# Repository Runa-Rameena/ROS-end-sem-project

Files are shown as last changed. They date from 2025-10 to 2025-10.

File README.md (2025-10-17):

# Snake Robot - Simulation & Hardware

## What We Simulated

We developed a complete ROS2 Humble + Gazebo Classic simulation of a modular snake robot with 33 articulated joints. The simulation models an 8-segment snake robot that performs serpentine locomotion through coordinated joint movements.

**Simulation Features:**
- 33 revolute joints with ±90° range of motion
- URDF/Xacro robot model with realistic physics properties
- ros2_control framework with joint_trajectory_controller
- Phase-shifted sinusoidal wave control algorithm
- Real-time visualization in RViz and Gazebo
- Keyboard teleop control (forward, backward, stop)
- Tunable gait parameters (amplitude, frequency, phase offset)

**Control Algorithm:**
Each joint follows a traveling wave equation:
θᵢ(t) = A · sin(ωt + φᵢ)
This creates smooth serpentine undulation where wave propagates along the body.

## What We Built in Hardware

We fabricated a physical 8-segment snake robot using 3D-printed PLA components and off-the-shelf electronics.

**Hardware Components:**
- 8× 3D-printed body segments (75×45×35 mm each)
- 1× head segment (85×45×45 mm) - houses ESP32 controller
- 1× tail segment (65×45×35 mm) - battery compartment
- 8× SG90 micro servo motors (4.8-6.0V, ±90°)
- ESP32 microcontroller (Arduino-compatible)
- 2S Li-Po battery (7.4V, 1000-2000 mAh)
- 5V 6A Buck converter for stable power regulation
- 470µF + 0.1µF capacitors for voltage filtering

**Power System:**
2S Li-Po (7.4V) → Buck Converter → 5V regulated output → Servos + ESP32

**Control Implementation:**
The same sinusoidal control algorithm from simulation was programmed into the ESP32. Each servo receives PWM signals with phase-shifted timing to create the traveling wave motion.

**Total Weight:** ~520g  

## Simulation-to-Hardware Validation

The hardware closely replicated the simulated motion:
- Amplitude: 25-30° (simulation: 25-35°)
- Frequency: 1-2.5 Hz (simulation: 1-3 Hz)  
- Phase coordination: 90%+ match between virtual and physical robot
- Continuous serpentine motion for 30+ minutes on single charge

Both systems use identical control logic, proving the simulation accurately predicts real-world snake locomotion.

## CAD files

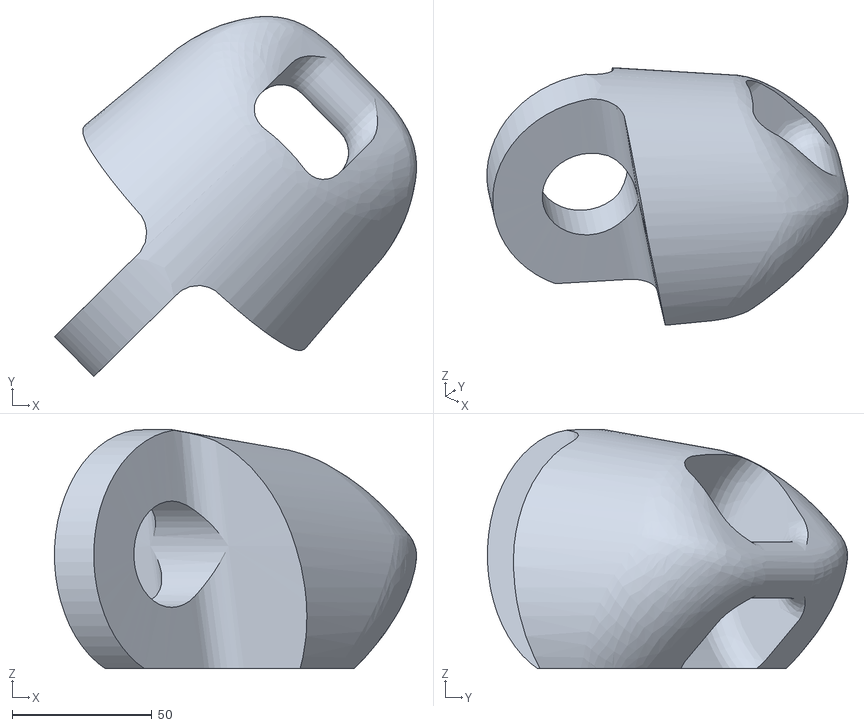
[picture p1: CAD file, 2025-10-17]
meshes/31_1.stl
129.4 x 128.7 x 85.5

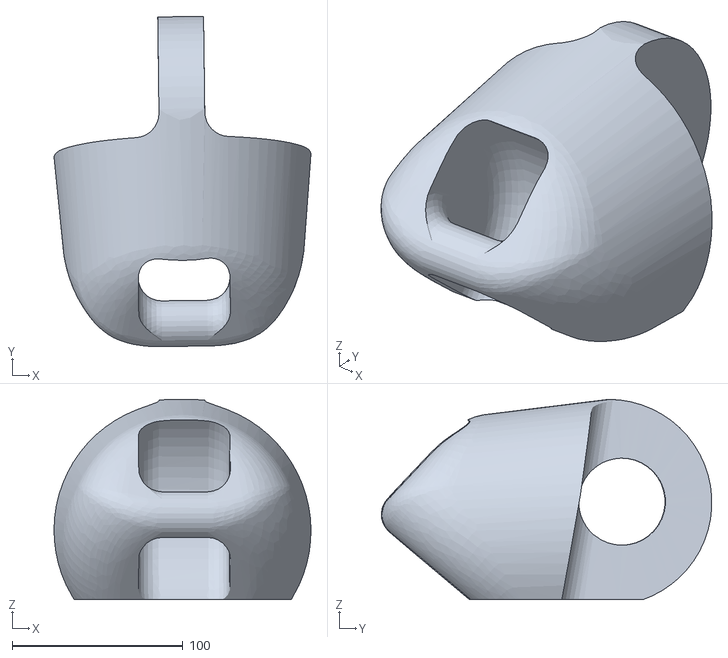
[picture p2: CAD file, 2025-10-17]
meshes/15_1.stl
150.5 x 193.5 x 117.2

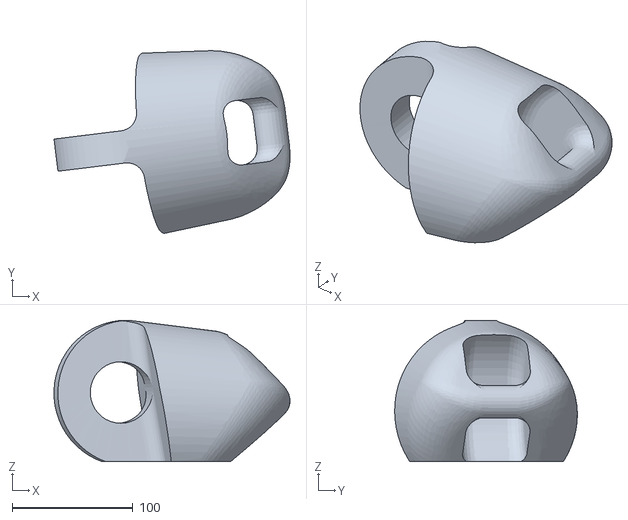
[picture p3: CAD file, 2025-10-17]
meshes/20_1.stl
195.7 x 151.5 x 117.2

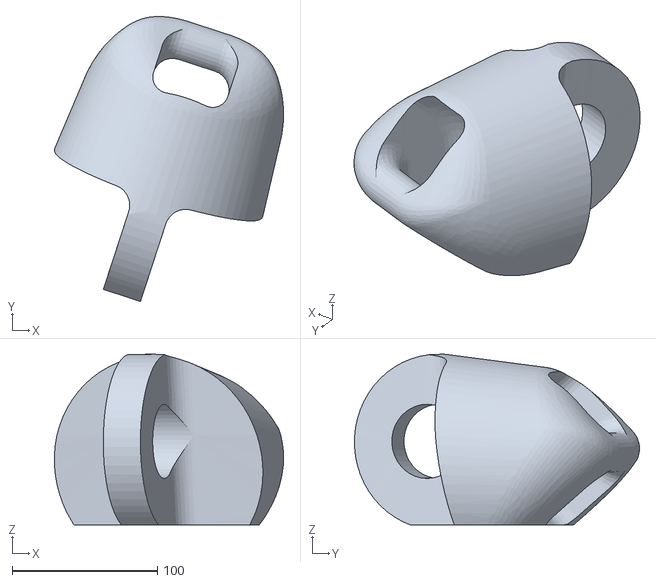
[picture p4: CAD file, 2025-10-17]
meshes/24_1.stl
157.5 x 195.9 x 117.2

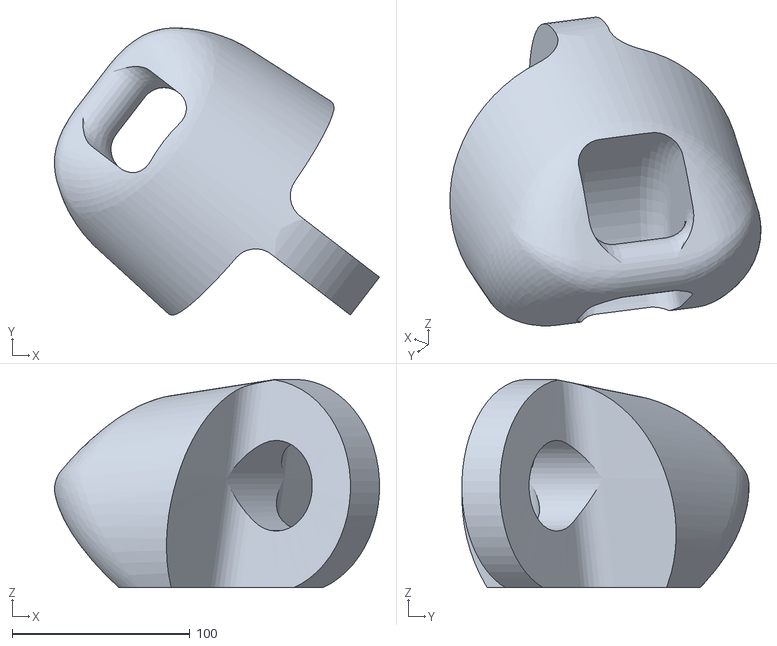
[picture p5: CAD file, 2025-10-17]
meshes/06_1.stl
182.8 x 161.5 x 117.2

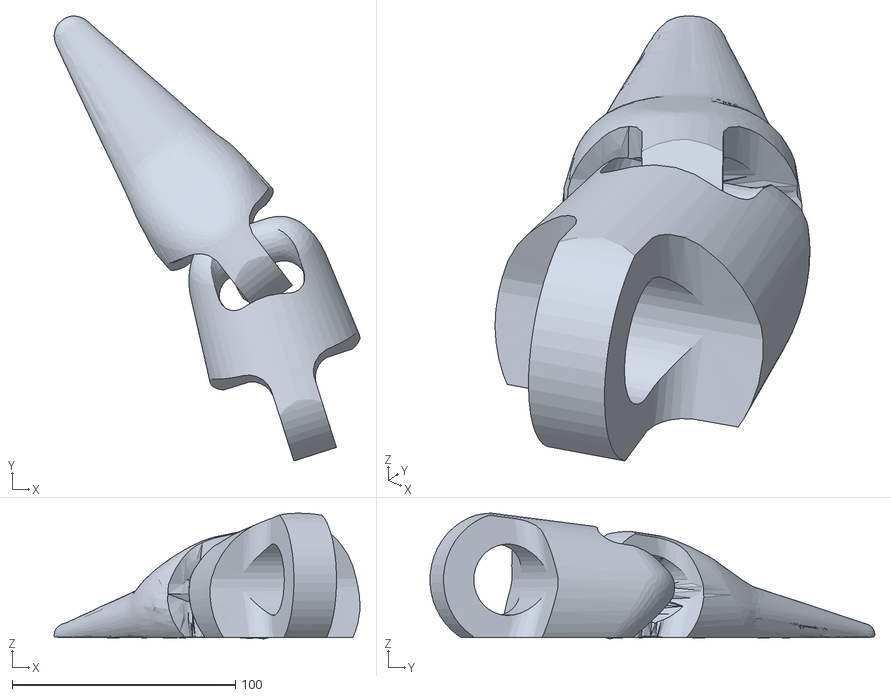
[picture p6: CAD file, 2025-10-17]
meshes/tail_1.stl
136.9 x 199.2 x 56.4

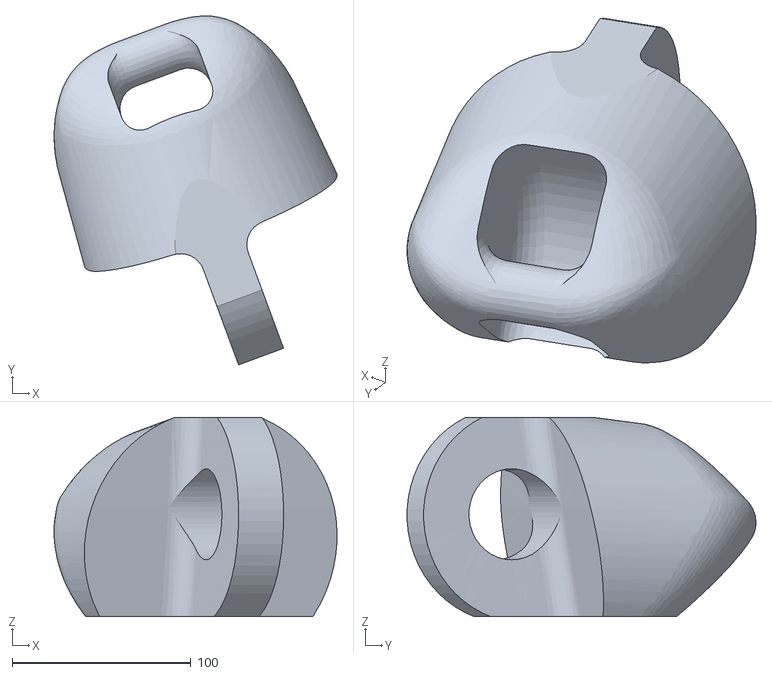
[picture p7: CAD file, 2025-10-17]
meshes/03_1.stl
158.4 x 195.3 x 111.7

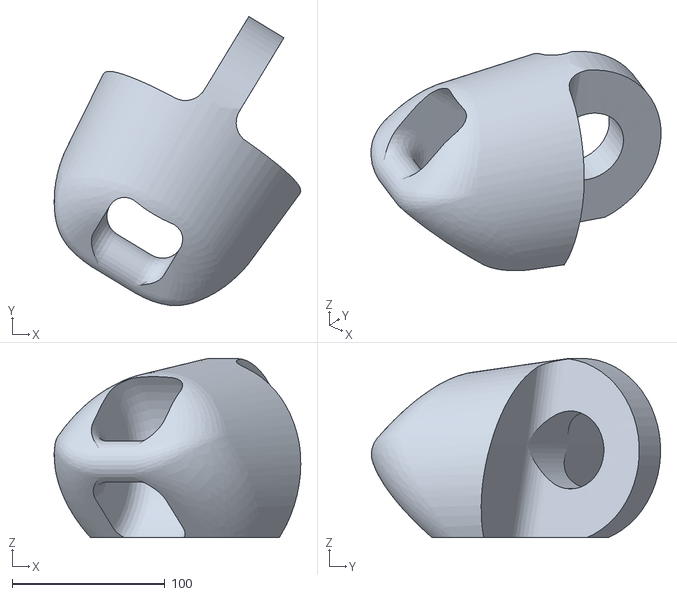
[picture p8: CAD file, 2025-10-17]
meshes/13_1.stl
161.2 x 188.9 x 117.2

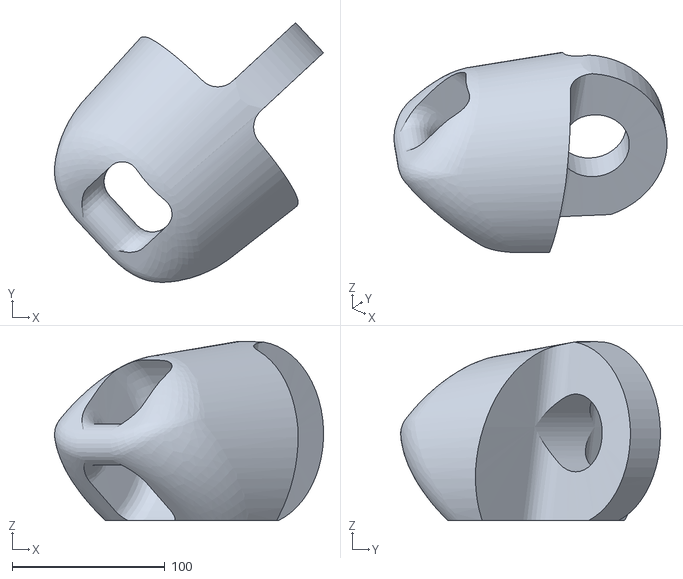
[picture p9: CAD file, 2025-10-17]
meshes/12_1.stl
176.2 x 170.1 x 117.2

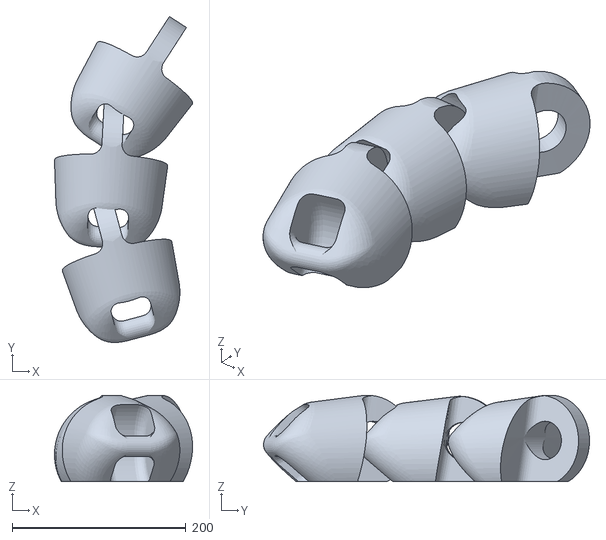
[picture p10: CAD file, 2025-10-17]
meshes/28_1.stl
159.0 x 375.3 x 99.5

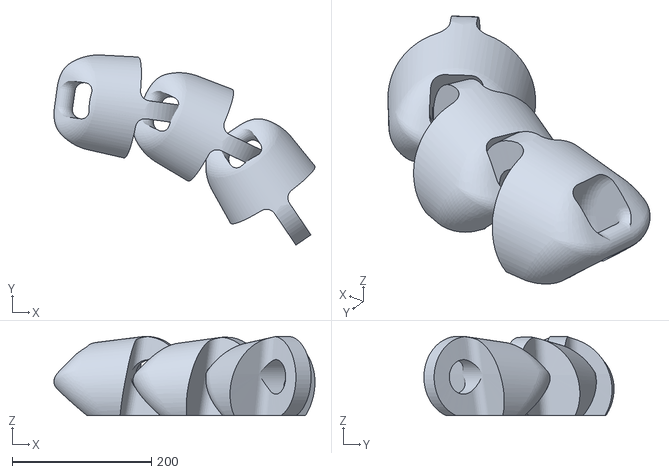
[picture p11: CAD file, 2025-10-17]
meshes/26_1.stl
374.8 x 273.0 x 113.9

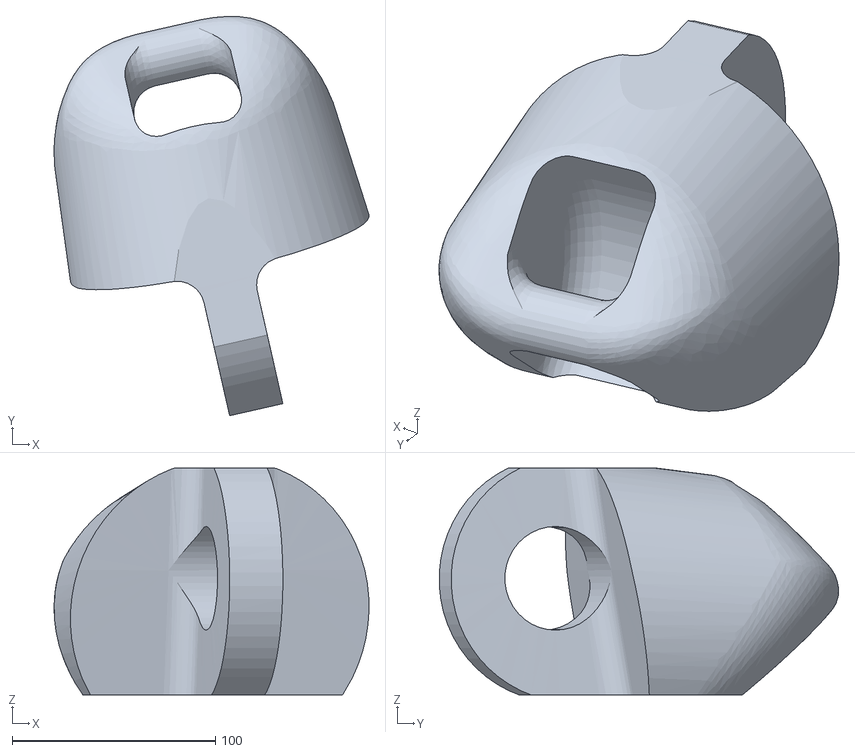
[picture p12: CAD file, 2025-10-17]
meshes/01_1.stl
155.0 x 196.5 x 111.6

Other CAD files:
meshes/09_1.stl
meshes/14_1.stl
meshes/11_1.stl
meshes/22_1.stl
meshes/04_1.stl
meshes/16_1.stl
meshes/02_1.stl
meshes/05_1.stl
meshes/07_1.stl
meshes/08_1.stl
meshes/10_1.stl
meshes/17_1.stl
meshes/18_1.stl
meshes/19_1.stl
meshes/21_1.stl
meshes/23_1.stl
meshes/25_1.stl
meshes/27_1.stl
meshes/29_1.stl
meshes/30_1.stl
meshes/32_1.stl
meshes/33_1.stl
meshes/base_link.stl

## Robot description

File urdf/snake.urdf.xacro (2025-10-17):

<?xml version="1.0"?>
<robot xmlns:xacro="http://www.ros.org/wiki/xacro" name="snake_robot">

  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
  <xacro:include filename="$(find snake_robot)/urdf/materials.xacro"/>

  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
  <link name="world"/>

  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
  <link name="base_link">
    <inertial>
      <origin xyz="0 0 0" rpy="0 0 0"/>
      <mass value="2.0"/>
      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
    </inertial>
    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
  </link>

  <joint name="world_joint" type="fixed">
    <parent link="world"/>
    <child link="base_link"/>
  </joint>

  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
  <link name="link1">
    <inertial>
      <origin xyz="0 0 0" rpy="0 0 0"/>
      <mass value="1.0"/>
      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
    </inertial>
    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
  </link>

  <joint name="joint1" type="revolute">
    <parent link="base_link"/>
    <child link="link1"/>
    <origin xyz="0.15 0 0" rpy="0 0 0"/>
    <axis xyz="0 0 1"/>
    <limit effort="10" velocity="2.0" lower="-1.57" upper="1.57"/>
    <dynamics damping="0.5" friction="0.1"/>
    <safety_controller k_position="100" k_velocity="10" soft_lower_limit="-1.5" soft_upper_limit="1.5"/>
  </joint>

  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
  <link name="link2">
    <inertial>
      <origin xyz="0 0 0" rpy="0 0 0"/>
      <mass value="1.0"/>
      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
    </inertial>
    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
  </link>

  <joint name="joint2" type="revolute">
    <parent link="link1"/>
    <child link="link2"/>
    <origin xyz="0.15 0 0" rpy="0 0 0"/>
    <axis xyz="0 0 1"/>
    <limit effort="10" velocity="2.0" lower="-1.57" upper="1.57"/>
    <dynamics damping="0.5" friction="0.1"/>
    <safety_controller k_position="100" k_velocity="10" soft_lower_limit="-1.5" soft_upper_limit="1.5"/>
  </joint>

  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
  <xacro:macro name="snake_segment" params="n">
    <link name="link${n}">
      <inertial>
        <origin xyz="0 0 0" rpy="0 0 0"/>
        <mass value="1.0"/>
        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
      </inertial>
      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
    </link>

    <joint name="joint${n}" type="revolute">
      <parent link="link${n - 1}"/>
      <child link="link${n}"/>
      <origin xyz="0.15 0 0" rpy="0 0 0"/>
      <axis xyz="0 0 1"/>
      <limit effort="10" velocity="2.0" lower="-1.57" upper="1.57"/>
      <dynamics damping="0.5" friction="0.1"/>
      <safety_controller k_position="100" k_velocity="10" soft_lower_limit="-1.5" soft_upper_limit="1.5"/>
    </joint>
  </xacro:macro>

  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
  <xacro:snake_segment n="3"/>
  <xacro:snake_segment n="4"/>
  <xacro:snake_segment n="5"/>
  <xacro:snake_segment n="6"/>
  <xacro:snake_segment n="7"/>
  <xacro:snake_segment n="8"/>
  <xacro:snake_segment n="9"/>
  <xacro:snake_segment n="10"/>
  <xacro:snake_segment n="11"/>
  <xacro:snake_segment n="12"/>
  <xacro:snake_segment n="13"/>
  <xacro:snake_segment n="14"/>
  <xacro:snake_segment n="15"/>
  <xacro:snake_segment n="16"/>
  <xacro:snake_segment n="17"/>
  <xacro:snake_segment n="18"/>
  <xacro:snake_segment n="19"/>
  <xacro:snake_segment n="20"/>
  <xacro:snake_segment n="21"/>
  <xacro:snake_segment n="22"/>
  <xacro:snake_segment n="23"/>
  <xacro:snake_segment n="24"/>
  <xacro:snake_segment n="25"/>
  <xacro:snake_segment n="26"/>
  <xacro:snake_segment n="27"/>
  <xacro:snake_segment n="28"/>
  <xacro:snake_segment n="29"/>
  <xacro:snake_segment n="30"/>
  <xacro:snake_segment n="31"/>
  <xacro:snake_segment n="32"/>
  <xacro:snake_segment n="33"/>

  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
  <link name="tail_link">
    <inertial>
      <origin xyz="0 0 0" rpy="0 0 0"/>
      <mass value="0.5"/>
      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
    </inertial>
    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
  </link>

  <joint name="joint34" type="fixed">
    <parent link="link33"/>
    <child link="tail_link"/>
    <origin xyz="0.15 0 0" rpy="0 0 0"/>
  </joint>

  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
  <ros2_control name="SnakeRobotSystem" type="system">
    <hardware>
      <plugin>gazebo_ros2_control/GazeboSystem</plugin>
    </hardware>

    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
    <joint name="joint1">
      <command_interface name="position"/>
      <state_interface name="position"/>
      <state_interface name="velocity"/>
      <state_interface name="effort"/>
      <param name="min">-1.57</param>
      <param name="max">1.57</param>
    </joint>

    <joint name="joint2">
      <command_interface name="position"/>
      <state_interface name="position"/>
      <state_interface name="velocity"/>
      <state_interface name="effort"/>
      <param name="min">-1.57</param>
      <param name="max">1.57</param>
    </joint>

    <xacro:macro name="snake_joint_control" params="n">
      <joint name="joint${n}">
        <command_interface name="position"/>
        <state_interface name="position"/>
        <state_interface name="velocity"/>
        <state_interface name="effort"/>
        <param name="min">-1.57</param>
        <param name="max">1.57</param>
      </joint>
    </xacro:macro>

    <xacro:snake_joint_control n="3"/>
    <xacro:snake_joint_control n="4"/>
    <xacro:snake_joint_control n="5"/>
    <xacro:snake_joint_control n="6"/>
    <xacro:snake_joint_control n="7"/>
    <xacro:snake_joint_control n="8"/>
    <xacro:snake_joint_control n="9"/>
    <xacro:snake_joint_control n="10"/>
    <xacro:snake_joint_control n="11"/>
    <xacro:snake_joint_control n="12"/>
    <xacro:snake_joint_control n="13"/>
    <xacro:snake_joint_control n="14"/>
    <xacro:snake_joint_control n="15"/>
    <xacro:snake_joint_control n="16"/>
    <xacro:snake_joint_control n="17"/>
    <xacro:snake_joint_control n="18"/>
    <xacro:snake_joint_control n="19"/>
    <xacro:snake_joint_control n="20"/>
    <xacro:snake_joint_control n="21"/>
    <xacro:snake_joint_control n="22"/>
    <xacro:snake_joint_control n="23"/>
    <xacro:snake_joint_control n="24"/>
    <xacro:snake_joint_control n="25"/>
    <xacro:snake_joint_control n="26"/>
    <xacro:snake_joint_control n="27"/>
    <xacro:snake_joint_control n="28"/>
    <xacro:snake_joint_control n="29"/>
    <xacro:snake_joint_control n="30"/>
    <xacro:snake_joint_control n="31"/>
    <xacro:snake_joint_control n="32"/>
    <xacro:snake_joint_control n="33"/>
  </ros2_control>

  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

</robot>

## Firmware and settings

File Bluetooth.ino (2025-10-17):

/*
 * ESP32 Snake Robot - Bluetooth RC Control with Debug Prints
 * Hardware: ESP32 DevKit V1 + 8x SG90 Servos
 * Control: Bluetooth RC Car App
 * Movements: Forward, Backward, Left, Right
 * 
 * Bluetooth RC Car App Commands:
 * 'F' - Forward
 * 'B' - Backward
 * 'L' - Left (Turn Left)
 * 'R' - Right (Turn Right)
 * 'S' - Stop
 */

#include <BluetoothSerial.h>
#include <ESP32Servo.h>

// Check if Bluetooth is available
#if !defined(CONFIG_BT_ENABLED) || !defined(CONFIG_BLUEDROID_ENABLED)
#error Bluetooth is not enabled! Please run `make menuconfig` to enable it
#endif

// Create Bluetooth Serial object
BluetoothSerial SerialBT;

// Create servo objects for 8 joints
Servo servo[8];

// GPIO pins for servos (as per circuit diagram)
const int servoPins[8] = {2, 4, 5, 18, 19, 21, 22, 23};

// Servo parameters
const int SERVO_MIN = 500;   // Minimum pulse width in microseconds
const int SERVO_MAX = 2500;  // Maximum pulse width in microseconds
const int SERVO_CENTER = 1500; // Center position (90 degrees)

// Gait parameters for snake locomotion
float amplitude = 0.6;        // Wave amplitude in radians (adjustable 0.2-0.8)
float frequency = 0.5;        // Temporal frequency in Hz
float spatialFreq = 0.8;      // Spatial frequency parameter

// Movement state
char currentCommand = 'S';    // Current movement command
bool isMoving = false;
unsigned long lastUpdateTime = 0;
const int UPDATE_INTERVAL = 50; // Update servo positions every 50ms

// Movement modes
enum MovementMode {
  FORWARD,
  BACKWARD,
  TURN_LEFT,
  TURN_RIGHT,
  STOPPED
};

MovementMode currentMode = STOPPED;

void setup() {
  // Initialize Serial Monitor
  Serial.begin(115200);
  Serial.println("\n\n========================================");
  Serial.println("ESP32 Snake Robot - Bluetooth RC Control");
  Serial.println("========================================");
  
  Serial.println("\n[SETUP] Starting initialization...");
  
  // Initialize Bluetooth with device name
  Serial.print("[BLUETOOTH] Initializing Bluetooth... ");
  SerialBT.begin("ESP32_SnakeBot"); // Bluetooth device name
  Serial.println("SUCCESS");
  Serial.println("[BLUETOOTH] Device name: ESP32_SnakeBot");
  Serial.println("[BLUETOOTH] Waiting for connection...");
  
  // Initialize servos
  Serial.println("\n[SERVO] Initializing 8 servos...");
  for (int i = 0; i < 8; i++) {
    Serial.print("[SERVO] Attaching Servo ");
    Serial.print(i);
    Serial.print(" to GPIO ");
    Serial.print(servoPins[i]);
    Serial.print("... ");
    
    servo[i].attach(servoPins[i], SERVO_MIN, SERVO_MAX);
    servo[i].writeMicroseconds(SERVO_CENTER);
    
    Serial.print("SUCCESS - Position set to ");
    Serial.print(SERVO_CENTER);
    Serial.println(" µs (neutral)");
  }
  
  delay(1000); // Allow servos to reach neutral position
  
  Serial.println("\n[SETUP] Initialization complete!");
  Serial.println("[SYSTEM] Ready to receive commands!");
  Serial.println("========================================");
  Serial.println("Waiting for Bluetooth connection...\n");
}

void loop() {
  // Check for incoming Bluetooth commands
  if (SerialBT.available()) {
    char received = SerialBT.read();
    Serial.print("\n[INPUT] Bluetooth data received: '");
    Serial.print(received);
    Serial.print("' (ASCII: ");
    Serial.print((int)received);
    Serial.println(")");
    
    processCommand(received);
  }
  
  // Update servo positions based on current movement mode
  if (isMoving && (millis() - lastUpdateTime >= UPDATE_INTERVAL)) {
    updateServoPositions();
    lastUpdateTime = millis();
  }
}

// Process incoming Bluetooth commands
void processCommand(char cmd) {
  currentCommand = cmd;
  
  Serial.print("[COMMAND] Processing command: '");
  Serial.print(cmd);
  Serial.print("' -> ");
  
  switch (cmd) {
    case 'F': // Forward
      Serial.println("FORWARD");
      currentMode = FORWARD;
      isMoving = true;
      Serial.println("[MOVEMENT] Setting mode: FORWARD");
      Serial.println("[MOVEMENT] Motion started: Serpenoid forward wave");
      Serial.print("[PARAMETERS] Amplitude: ");
      Serial.print(amplitude);
      Serial.print(" rad, Frequency: ");
      Serial.print(frequency);
      Serial.print(" Hz, Spatial Freq: ");
      Serial.println(spatialFreq);
      break;
      
    case 'B': // Backward
      Serial.println("BACKWARD");
      currentMode = BACKWARD;
      isMoving = true;
      Serial.println("[MOVEMENT] Setting mode: BACKWARD");
      Serial.println("[MOVEMENT] Motion started: Reversed serpenoid wave");
      Serial.print("[PARAMETERS] Amplitude: ");
      Serial.print(amplitude);
      Serial.print(" rad, Frequency: ");
      Serial.print(frequency);
      Serial.print(" Hz, Spatial Freq: ");
      Serial.println(spatialFreq);
      break;
      
    case 'L': // Turn Left
      Serial.println("TURN LEFT");
      currentMode = TURN_LEFT;
      isMoving = true;
      Serial.println("[MOVEMENT] Setting mode: TURN_LEFT");
      Serial.println("[MOVEMENT] Motion started: Left-biased wave pattern");
      Serial.println("[PARAMETERS] Bias: -0.3 rad (left curve)");
      break;
      
    case 'R': // Turn Right
      Serial.println("TURN RIGHT");
      currentMode = TURN_RIGHT;
      isMoving = true;
      Serial.println("[MOVEMENT] Setting mode: TURN_RIGHT");
      Serial.println("[MOVEMENT] Motion started: Right-biased wave pattern");
      Serial.println("[PARAMETERS] Bias: +0.3 rad (right curve)");
      break;
      
    case 'S': // Stop
      Serial.println("STOP");
      currentMode = STOPPED;
      isMoving = false;
      stopRobot();
      Serial.println("[MOVEMENT] Setting mode: STOPPED");
      Serial.println("[MOVEMENT] All servos returned to neutral position");
      break;
      
    default:
      Serial.print("UNKNOWN (ignored)");
      Serial.println("\n[WARNING] Unrecognized command, ignoring");
      break;
  }
  
  Serial.println("--------------------");
}

// Update servo positions based on serpenoid gait
void updateServoPositions() {
  float t = millis() / 1000.0; // Current time in seconds
  
  Serial.print("[UPDATE] Time: ");
  Serial.print(t, 3);
  Serial.print("s | Mode: ");
  
  switch (currentMode) {
    case FORWARD:
      Serial.print("FORWARD");
      break;
    case BACKWARD:
      Serial.print("BACKWARD");
      break;
    case TURN_LEFT:
      Serial.print("TURN_LEFT");
      break;
    case TURN_RIGHT:
      Serial.print("TURN_RIGHT");
      break;
    case STOPPED:
      Serial.print("STOPPED");
      break;
  }
  
  Serial.println(" | Servo positions:");
  
  for (int i = 0; i < 8; i++) {
    float angle = 0.0;
    
    switch (currentMode) {
      case FORWARD:
        // Forward serpenoid wave: lateral undulation
        angle = amplitude * sin(2 * PI * frequency * t - spatialFreq * i);
        break;
        
      case BACKWARD:
        // Backward: reverse the wave direction
        angle = amplitude * sin(2 * PI * frequency * t + spatialFreq * i);
        break;
        
      case TURN_LEFT:
        // Left turn: asymmetric wave with bias to left
        angle = amplitude * sin(2 * PI * frequency * t - spatialFreq * i) - 0.3;
        break;
        
      case TURN_RIGHT:
        // Right turn: asymmetric wave with bias to right
        angle = amplitude * sin(2 * PI * frequency * t - spatialFreq * i) + 0.3;
        break;
        
      case STOPPED:
        angle = 0.0; // All joints to neutral
        break;
    }
    
    // Convert radians to microseconds for servo
    int pulseWidth = radiansToMicroseconds(angle);
    
    // Output to servo
    servo[i].writeMicroseconds(pulseWidth);
    
    // Print servo state
    Serial.print("  [SERVO ");
    Serial.print(i);
    Serial.print(" | GPIO ");
    Serial.print(servoPins[i]);
    Serial.print("] Angle: ");
    if (angle >= 0) Serial.print("+");
    Serial.print(angle, 3);
    Serial.print(" rad (");
    Serial.print(angle * 57.2958, 1); // Convert to degrees
    Serial.print("°) -> Pulse: ");
    Serial.print(pulseWidth);
    Serial.println(" µs");
  }
  
  Serial.println("--------------------\n");
}

// Stop all servos (return to neutral position)
void stopRobot() {
  Serial.println("[STOP] Stopping all servos...");
  
  for (int i = 0; i < 8; i++) {
    servo[i].writeMicroseconds(SERVO_CENTER);
    
    Serial.print("  [SERVO ");
    Serial.print(i);
    Serial.print(" | GPIO ");
    Serial.print(servoPins[i]);
    Serial.print("] Set to NEUTRAL (");
    Serial.print(SERVO_CENTER);
    Serial.println(" µs)");
  }
  
  Serial.println("[STOP] All servos stopped");
}

// Convert angle in radians to servo pulse width in microseconds
int radiansToMicroseconds(float radians) {
  // Map radians to servo pulse width
  // -PI/2 to PI/2 maps to SERVO_MIN to SERVO_MAX
  // Clamp to ±90 degrees (±1.57 radians)
  float originalRadians = radians;
  radians = constrain(radians, -1.57, 1.57);
  
  // Check if clamping occurred
  if (originalRadians != radians) {
    Serial.print("    [LIMIT] Angle clamped from ");
    Serial.print(originalRadians, 3);
    Serial.print(" to ");
    Serial.print(radians, 3);
    Serial.println(" rad");
  }
  
  // Map to pulse width
  int pulseWidth = map(radians * 1000, -1570, 1570, SERVO_MIN, SERVO_MAX);
  return pulseWidth;
}

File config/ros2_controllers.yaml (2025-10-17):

controller_manager:
  ros__parameters:
    update_rate: 100  # Increased from default
    joint_state_broadcaster:
      type: joint_state_broadcaster/JointStateBroadcaster
    joint_trajectory_controller:
      type: joint_trajectory_controller/JointTrajectoryController

joint_state_broadcaster:
  ros__parameters: {}

joint_trajectory_controller:
  ros__parameters:
    joints: [joint1, joint2, joint3, joint4, joint5, joint6, joint7, joint8,
             joint9, joint10, joint11, joint12, joint13, joint14, joint15,
             joint16, joint17, joint18, joint19, joint20, joint21, joint22,
             joint23, joint24, joint25, joint26, joint27, joint28, joint29,
             joint30, joint31, joint32, joint33]
    command_interfaces:
      - position
    state_interfaces:
      - position
      - velocity
    constraints:
      goal_time: 0.5
      stopped_velocity_tolerance: 0.01
    gains:  # PID gains for position control
      joint1: {p: 100.0, i: 0.01, d: 10.0, i_clamp: 1.0}
      joint2: {p: 100.0, i: 0.01, d: 10.0, i_clamp: 1.0}
      joint3: {p: 100.0, i: 0.01, d: 10.0, i_clamp: 1.0}
      joint4: {p: 100.0, i: 0.01, d: 10.0, i_clamp: 1.0}
      joint5: {p: 100.0, i: 0.01, d: 10.0, i_clamp: 1.0}
      joint6: {p: 100.0, i: 0.01, d: 10.0, i_clamp: 1.0}
      joint7: {p: 100.0, i: 0.01, d: 10.0, i_clamp: 1.0}
      joint8: {p: 100.0, i: 0.01, d: 10.0, i_clamp: 1.0}
      joint9: {p: 100.0, i: 0.01, d: 10.0, i_clamp: 1.0}
      joint10: {p: 100.0, i: 0.01, d: 10.0, i_clamp: 1.0}
      joint11: {p: 100.0, i: 0.01, d: 10.0, i_clamp: 1.0}
      joint12: {p: 100.0, i: 0.01, d: 10.0, i_clamp: 1.0}
      joint13: {p: 100.0, i: 0.01, d: 10.0, i_clamp: 1.0}
      joint14: {p: 100.0, i: 0.01, d: 10.0, i_clamp: 1.0}
      joint15: {p: 100.0, i: 0.01, d: 10.0, i_clamp: 1.0}
      joint16: {p: 100.0, i: 0.01, d: 10.0, i_clamp: 1.0}
      joint17: {p: 100.0, i: 0.01, d: 10.0, i_clamp: 1.0}
      joint18: {p: 100.0, i: 0.01, d: 10.0, i_clamp: 1.0}
      joint19: {p: 100.0, i: 0.01, d: 10.0, i_clamp: 1.0}
      joint20: {p: 100.0, i: 0.01, d: 10.0, i_clamp: 1.0}
      joint21: {p: 100.0, i: 0.01, d: 10.0, i_clamp: 1.0}
      joint22: {p: 100.0, i: 0.01, d: 10.0, i_clamp: 1.0}
      joint23: {p: 100.0, i: 0.01, d: 10.0, i_clamp: 1.0}
      joint24: {p: 100.0, i: 0.01, d: 10.0, i_clamp: 1.0}
      joint25: {p: 100.0, i: 0.01, d: 10.0, i_clamp: 1.0}
      joint26: {p: 100.0, i: 0.01, d: 10.0, i_clamp: 1.0}
      joint27: {p: 100.0, i: 0.01, d: 10.0, i_clamp: 1.0}
      joint28: {p: 100.0, i: 0.01, d: 10.0, i_clamp: 1.0}
      joint29: {p: 100.0, i: 0.01, d: 10.0, i_clamp: 1.0}
      joint30: {p: 100.0, i: 0.01, d: 10.0, i_clamp: 1.0}
      joint31: {p: 100.0, i: 0.01, d: 10.0, i_clamp: 1.0}
      joint32: {p: 100.0, i: 0.01, d: 10.0, i_clamp: 1.0}
      joint33: {p: 100.0, i: 0.01, d: 10.0, i_clamp: 1.0}
    hold_trajectory_duration: 0.1
    velocity_ff_gain: 1.0
    state_publish_rate: 100.0
    action_monitor_rate: 20.0
